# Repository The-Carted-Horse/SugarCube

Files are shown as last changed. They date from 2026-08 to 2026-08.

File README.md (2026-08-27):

# GlucoCube

A wall-mounted glucose dashboard for two (or more) people, built for a
Raspberry Pi with the official 7" touchscreen. It boots straight into the
display — no desktop environment — and shows each person's current glucose,
trend, a 3-hour history chart, a 2-hour forecast, insulin on board, carbs on
board, and recent treatments.

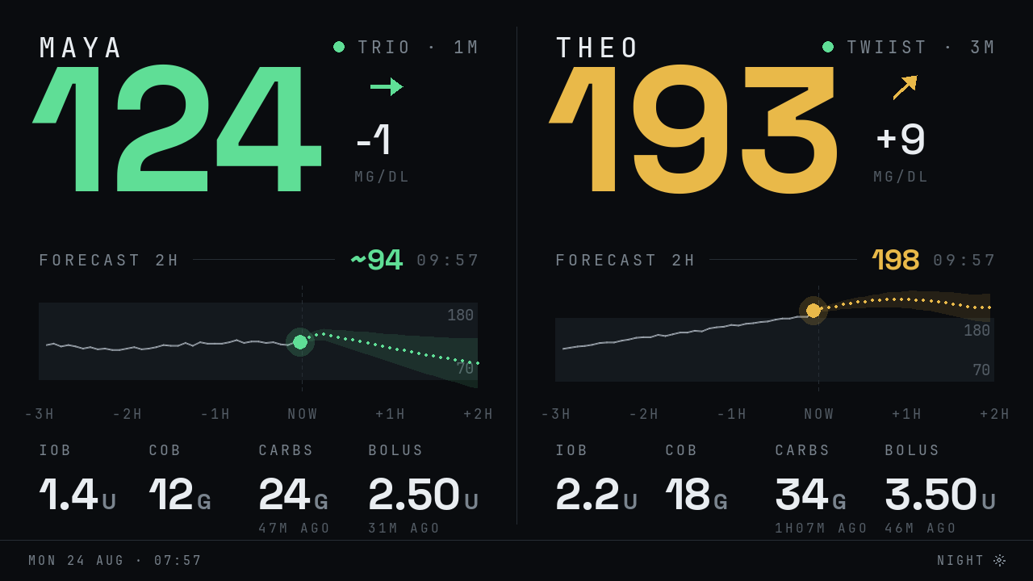
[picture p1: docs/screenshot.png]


## Features

- **Per-person data sources** — each person's data can arrive by:
  - **Push**: point a [Trio](https://github.com/nightscout/Trio) (or any
    Nightscout uploader) at the Pi — it speaks a minimal Nightscout v1 API,
    one port per person
  - **Pull from Tidepool** — for the twiist AID system, which uploads to
    Tidepool automatically; readings, boluses, carbs, IOB/COB, and pump
    settings all come across
  - **Pull from a Nightscout site** — for people with an existing cloud
    Nightscout; API secrets and access tokens both work (auto-detected)
- **Glucose forecast** — a 2-hour forecast curve with a confidence band on
  every chart, plus the projected value 2 hours out: uses the AID system's
  own prediction when available (Trio's `predBGs`, Loop's `predicted`),
  otherwise runs an oref0-style model (exponential insulin activity,
  deviation-based carb absorption) with therapy settings pulled from the
  person's Nightscout profile or Tidepool pump settings. Estimates are
  marked with `~`.
- **Web app** — the same dashboard in any browser, auto-refreshing,
  responsive, with light/dark themes. Settings (people, sources, thresholds)
  and a sync log are managed from the browser too; no SSH needed after
  install. Works great through a Cloudflare tunnel.
- **Touchscreen controls** — tap the sun/moon on the display for light or
  dark, and **SETTINGS** beside it to pop a QR code that opens the
  settings page on a phone, already signed in. The panel is read directly
  from `/dev/input`, so both work on the ready-made image as well as on a
  manual install; the theme switch is on the settings page too.
- **Update channels** — standard releases, or beta with the pre-releases
  as well; switching channels moves the device onto that channel's newest
  release straight away.
- **Per-person thresholds** — low/high/urgent ranges per person, with
  global defaults.
- **mg/dL or mmol/L** — chosen under **Settings → Ranges**, or followed from
  a paired GlucoCore account. Readings, the change since the last one, the
  forecast and the chart's band all read in it, on the display and in the
  web app. Everything stored stays mg/dL, `/api/dashboard.json` included, so
  switching converts what is shown rather than moving any threshold.
- **Guided setup from a phone** — a fresh device shows a QR code that opens
  a step-by-step wizard: Wi-Fi, where in the world it is so the clock is
  right, and the pairing code from GlucoCore that says who it shows, one
  question per screen. Credentials are
  tested before they're saved, and nothing is written until the last step.
  With no network at all the device opens its own setup hotspot — join it
  and the wizard opens by itself, no second QR code to scan. Once a network
  is chosen the device reboots onto it and shows its new address (also
  reachable as `http://glucocube.local/` on the ready-made image).

## Install

### Option A: flash the ready-made image

Grab `glucocube-<version>.img.xz` from the
[releases page](https://github.com/The-Carted-Horse/SugarCube/releases),
flash it with Raspberry Pi Imager (or `dd`), boot the Pi, and follow the
QR codes on screen. That's the whole install.

(Images are built by the `Build and release` GitHub Actions workflow, which
runs on every push to `main` — see [Cutting a release](#cutting-a-release).)

### Option B: install on an existing Raspberry Pi OS

Use Raspberry Pi OS **Lite** (no desktop needed):

```bash
curl -sSL https://raw.githubusercontent.com/The-Carted-Horse/SugarCube/main/install.sh | bash
```

The installer handles everything: dependencies, config with random secrets,
console screen-blanking, and a systemd service that starts on boot. It
finishes by printing the URL and API secret for each person's uploader.

## Connecting the data

- **Trio (push)**: in Trio, Settings → Services → Nightscout, set URL
  `http://<pi-ip>:<port>` and the person's API secret (both shown by the
  installer and on the web settings page).
- **twiist**: the wearer links their My twiist Portal account to a free
  [Tidepool](https://www.tidepool.org) account (one-time), then enter the
  Tidepool login in the web settings under their data source.
- **Nightscout**: enter the site URL and its API secret or access token.
- **GlucoCore**: three ways in, under **Settings → GlucoCore** or during
  guided setup, and they end in the same place.
  - **Scan it.** An unpaired display asks GlucoCore to pair it and shows the
    request as a QR code, on its own screen and on the settings page. Scan it
    with a phone that is signed in, choose who the display shows, approve —
    and it pairs itself. Nothing is typed at the display, and it never
    handles the account password. The code on the wall carries a request id
    and nothing else; the secret that collects the token stays on the device.
  - **Sign in on the display.** Email and password, used once to create the
    display in GlucoCore. Only the read-only device token is kept.
  - **Type a pairing code.** In GlucoCore, open **Devices** and create one:
    six digits, ten minutes, single use.

  Pairing adds those people to the display — anyone already fed by Trio,
  twiist or Nightscout keeps the source they have. Who appears, what they are
  called and their ranges then follow what GlucoCore says. Unpairing turns
  them back into uploader-fed people, each with their own port and API
  secret.

## The web app

Everything is served on plain HTTP port 80 — open `http://glucocube.local/`
(or the IP shown on the device's screen; HTTP Basic auth, login shown
there too). Every QR code the device puts on its screen carries the login
with it, so scanning one opens the page signed in — tap **SETTINGS** in
the footer of the display to get one for the settings page. The password
is printed under each code for anyone typing the address by hand.

The installer sets a random password, and **Access** can turn it off
again: on a home network you trust, the device is only reachable from
that network, and no password means nothing to look up on a phone. Then
the settings hub stops asking you to set one. On a network guests,
flatmates or an office share, keep it.

The `.local` name needs mDNS — iPhones, Macs, Windows, and Android 12+
all resolve it; on older Android type the IP instead. When port 80 isn't
available (e.g. running by hand on a dev machine) it falls back to 8080.

| Path | What |
|---|---|
| `/` | Live dashboard (auto-refreshes every 30s) |
| `/setup` | Guided setup, one question per screen |
| `/settings` | Everything else, one page per thing |
| `/log` | Sync activity from every data source |
| `/screen.png` | What the physical screen shows right now |
| `/api/dashboard.json` | The dashboard's data, as JSON |

Settings is a hub rather than one long form: each row says what it is set
to now — who is configured and when their last reading arrived, the
ranges, the network, the time zone, the version and channel — and opens a
short page for that one thing. Every person has their own page, with only
the fields their data source actually needs. Saving restarts the display
(a few seconds) and the page waits for it to come back rather than
guessing.

| Page | What is on it |
|---|---|
| `/settings/screen` | Live view of the physical screen, and Day/Night |
| `/settings/people` | One row per person, then a page each |
| `/settings/glucocore` | Pair this display with a GlucoCore code, or unpair it |
| `/settings/ranges` | mg/dL or mmol/L, in-range and urgent thresholds, staleness |
| `/settings/network` | Wi-Fi: what it is on, and what else is nearby |
| `/settings/clock` | Time zone (with what your phone thinks it is) |
| `/settings/updates` | Version, release channel, install |
| `/settings/access` | Password (or none at all), and a link that opens settings without logging in |

## Wi-Fi setup

A device with no network opens its own `GlucoCube-Setup` hotspot and shows
a QR code that joins a phone to it. Once the phone is on that hotspot the
setup page opens by itself — the device answers the connectivity check
every phone makes on joining a network, which is what makes the "sign in
to network" sheet appear. The page lists the networks the device saw
before the hotspot came up: tap one, or choose **Other network** for a
hidden or out-of-range one, and enter the password (with a Show button,
so you can check it before committing).

The hotspot drops while the device tries to connect, so the phone loses
that page; that is expected. If the join succeeds the device reboots, its
screen shows the new address, and reopening setup picks up where you left
off. If it fails, the hotspot comes back within a minute or two and **the
reason appears both on the device's own screen and at the top of the page**
(wrong password, network not found, and so on) — no SSH needed to find out
what went wrong.

### What a paired display takes from GlucoCore

Who it shows and in what order, what they are called, the in-range and
urgent bands, the time zone, the clock format, the staleness cutoff — and
the backlight: a daytime brightness and a dimmer night-time one, with the
hours between which the night figure applies (equal hours mean never).
Dimming needs a panel with a backlight under `/sys/class/backlight`, which
the official 7" display has and an HDMI monitor does not; without one the
setting is simply ignored.

It also takes how the people share the screen, and the art behind them —
see [Ambient mode](#ambient-mode). A background chosen in GlucoCore is
fetched once and kept, so a display redraws from its own copy and only
re-downloads when the picture actually changes.

GlucoCore can still send settings this display does nothing with — the
alert toggles, because this is not an alarm device (see
[Safety note](#safety-note)). Each config push logs what it did not apply,
so "I changed it and nothing happened" has an answer in
[`/log`](#the-web-app).

### Ambient mode

A second way to draw the screen, for a display that lives on a nightstand
or a desk rather than a kitchen wall: **one person at a time, full-bleed,
over a background**, with the time and the weather in the corner and
everything else anchored out of the middle so the picture stays visible.
The two-panel dashboard is unchanged and is still what a display shows by
default; **Settings → The screen** switches between them, and a tap on the
ambient screen brings the usual footer back for a few seconds so the
sun/moon and the settings QR are still one press away.

Backgrounds come from three places: four the device draws itself, anything
uploaded on a person's settings page, and anything chosen in GlucoCore. A
person can have their own, the display can have one for everyone else, and
a person can be set to *nothing* — which is not the same as unset, and is
how you keep a picture off one person on your own wall when they have
chosen one for themselves.

The art is dimmed, by a figure you set, and dimmed further overnight. That
is not a style choice: the reading has to stay readable over whatever is
behind it. For the same reason the border carries the glucose state
whatever the picture is doing, a stale reading still goes grey and drops
its arrow, and **an urgent reading holds the screen** rather than taking
its turn — see the [Safety note](#safety-note).

The weather is off until you say where the device is, under
**Settings → Weather**. It asks [Open-Meteo](https://open-meteo.com/),
which needs no account and no key, every fifteen minutes; a town name is
looked up once, when you save it. Guessing a location from the time zone
would need a coordinate table on the device and would confidently show the
wrong town's sky, so it does not.

### From GlucoCore's devices screen

A paired display collects the commands queued for it — on its realtime
channel when it has one, otherwise within the minute — and says what it
did with each, so the devices screen shows the outcome rather than a
silence:

| Command | On this display |
|---|---|
| Identify | Flashes a band across the screen for 30 seconds |
| Restart | Restarts the display; it comes back in a few seconds |
| Refresh now | Polls every pull source immediately |
| Clear cache | Drops stored readings and fetches again (therapy settings stay) |
| Check for updates | Runs the release check, and installs a forced release |

The heartbeat carries the version it is running and the config version it
has applied, which is what lets that screen tell a display that is behind
from one that is simply offline.

## Updates

### Upgrading from 1.x (SugarCube)

**Re-flash the card.** Version 2 renames the Python package, the service and
the paths, and 1.x's updater cannot install it: it looks for a package by the
old name. What happens when you press Install depends on how 1.x was put on:

- **From the ready-made image** — the update fails before anything is
  touched. The device carries on running 1.x, and simply never updates again.
- **From `install.sh` (a git checkout)** — do not press Install. The checkout
  succeeds, the service is left pointing at a module that no longer exists,
  and it restart-loops with no automatic way back. Recovering needs SSH.

Flashing a version 2 image is the supported route, and settings are entered
again through the setup wizard. To keep a 1.x device exactly as it is, leave
it alone — it will offer the update but cannot complete it.

The device checks GitHub for new [releases](https://github.com/The-Carted-Horse/SugarCube/releases)
every 6 hours. When one is available it shows up on the display footer, the
web dashboard, and the settings page — install it from **Settings →
Updates** (the display restarts, data is untouched). A release whose notes
contain `[force-update]` installs itself automatically at the device's next
check — use that for fixes every device should have.

### Release channels

**Settings → Updates** chooses which releases a device follows:

- **Standard** — full releases only, the ones `main` publishes. The default.
- **Beta** — the pre-releases `dev` publishes as well, for anyone happy to
  find the rough edges first.

Changing the channel installs that channel's newest release immediately,
rather than waiting for the next thing to be published. Leaving Beta
therefore steps *back* onto the last full release, which is the point: the
channel decides which releases the device runs, not just which ones it is
told about. A device that ends up on a pre-release with Standard selected
says so on the settings page, and offers the way back.

The channel is stored in `config.json`:

```json
{ "updates": { "channel": "beta" } }
```

### Cutting a release

Releases are cut by pushing, not by tagging:

- **Push to `dev`** — builds an image and publishes `vX.Y.Z-rc.N` as a
  GitHub *pre-release*. Devices on the Standard channel never see it;
  devices set to Beta are offered it at their next check, and the attached
  image can be flashed to try it. Each further push to `dev` bumps `N`.
- **Push to `main`** — builds an image and publishes `vX.Y.Z` as a full
  release. This is the one existing devices offer under Settings → Updates.
  It takes the version the `dev` rcs were rehearsing (`2.0.1-rc.3` →
  `2.0.1`), or bumps the patch number if `dev` never rehearsed one.

Both create their tag at the commit that was pushed, so there is no tag to
push by hand.

For a minor or major bump — or to run either channel off another branch —
run the workflow manually and pick the part to increment and the channel.

A push that changes nothing a device runs publishes nothing: prose, the
enclosure, the test suite and tool config are excluded on both channels,
because a release whose code is identical to the last one would still be
offered to every device on it. Everything else still cuts one, `install.sh`
and the systemd units included. To publish anyway, run the workflow by
hand — the exclusions apply to pushes only.

## Enclosure

[`enclosure/`](enclosure/) has a printable OpenSCAD enclosure for the 7"
display module — see `enclosure.scad` and the ready-to-slice STLs in
`enclosure/build/`. It was designed by Sarah Sabanis and is licensed
separately, under [CC BY-NC-SA 4.0](enclosure/LICENSE).

## Development

Runs on a Mac/PC in a window with fake data:

```bash
pip install pygame qrcode
python -m glucocube --demo --windowed
```

`--no-display` runs the servers headless — useful for working on the web UI,
since nothing it serves needs pygame. `--screenshot out.png` renders one
frame and exits.

If the touchscreen is mounted rotated relative to the panel, correct it
with `GLUCOCUBE_TOUCH_TRANSFORM` — a comma-separated list of `swap`,
`invx` and `invy` — in the systemd unit. `GLUCOCUBE_TOUCH=off` disables
reading the panel altogether. The runtime dependencies are `pygame` and
`qrcode`, plus `websocket-client` for GlucoCore's realtime channel — a
config change then reaches the display in seconds rather than at the next
poll, and without the package it long-polls instead. All three come from
apt on the Pi; everything else is the Python standard library.
The display and web app are typeset in
[Space Grotesk](https://github.com/floriankarsten/space-grotesk) and
[JetBrains Mono](https://github.com/JetBrains/JetBrainsMono), bundled under
the SIL Open Font License in `glucocube/fonts/`.

### Tests

The suite is standard `pytest`, and needs no hardware — the display is
rendered through SDL's dummy driver (the same one the shipped image uses),
NetworkManager and every outbound HTTP call are stubbed out, and the
end-to-end tests start `python -m glucocube` in a subprocess and talk to
it over sockets:

```bash
pip install -r requirements-dev.txt
pytest                       # the whole suite, about fifteen seconds
pytest tests/test_oref.py    # one module
pytest --cov=glucocube       # with coverage
ruff check glucocube tests   # the same lint CI runs
```

The `Tests` workflow runs all of it on Python 3.11, 3.12 and 3.13,
alongside `shellcheck` over `install.sh` and the image stage scripts and
`systemd-analyze verify` over the service units. The release build calls
that same workflow and waits for it, so nothing is published from a red
tree.

## Safety note

This is a convenience display, not a medical device. Forecasts are estimates
— even the pump-provided ones. Don't rely on it for alarms or treatment
decisions; use the CGM app's own alerts for that. The same, in operative
terms, is in [`LICENSE`](LICENSE), so that it travels with every copy.

## License

GlucoCube is free to use for personal and other noncommercial purposes,
under the [PolyForm Noncommercial License 1.0.0](LICENSE) — that covers
personal and hobby use, study and research, and use by charities, schools,
public health bodies and government, whatever their funding. Commercial use
needs written permission: open an issue to ask.

Three things in this repository are **not** under those terms:

- The **enclosure** is Sarah Sabanis's design, under
  [CC BY-NC-SA 4.0](enclosure/LICENSE).
- The **bundled fonts** in `glucocube/fonts/` stay solely under the SIL Open
  Font License 1.1. Your rights in them, commercial use included, are
  untouched by the license above — the OFL requires exactly that.
- The **SD card image** is Raspberry Pi OS, and every package in it keeps its
  own license. GlucoCube's terms reach only the GlucoCube layer.

The glucose forecast reimplements the exponential insulin-activity model
from [oref0](https://github.com/openaps/oref0) in Python. Raspberry Pi,
Nightscout, Trio, Tidepool, twiist, Loop and OpenAPS are their owners'
names, used here only to say what works with what.

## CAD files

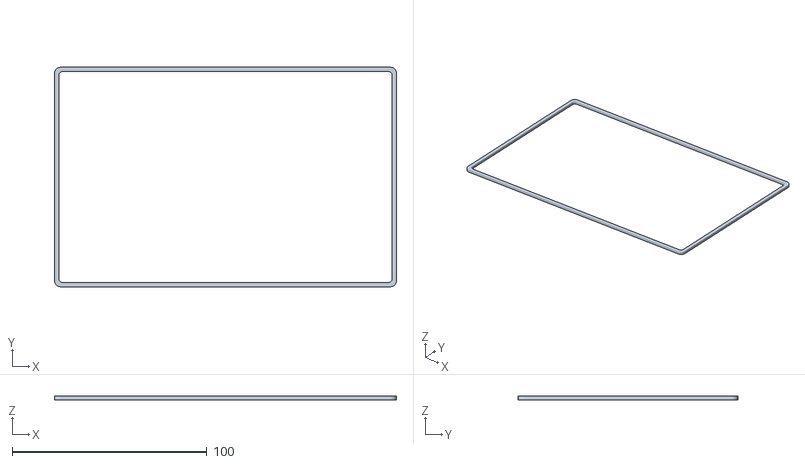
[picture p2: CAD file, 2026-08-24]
enclosure/build/gasket_flange.stl
175.7 x 112.8 x 1.80

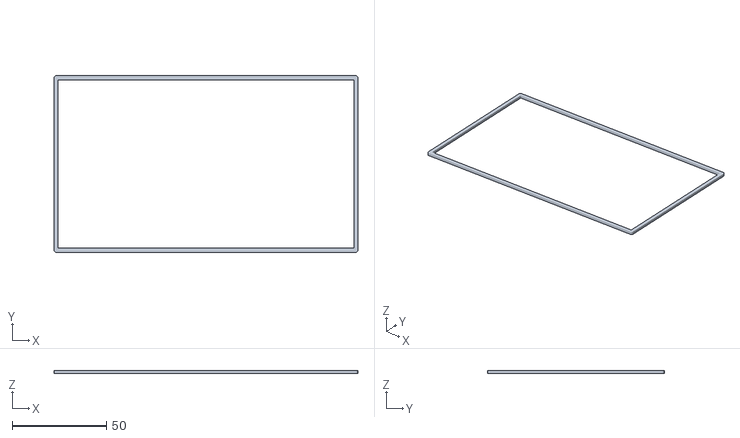
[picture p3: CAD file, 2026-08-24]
enclosure/build/gasket_window.stl
161.5 x 93.8 x 1.80

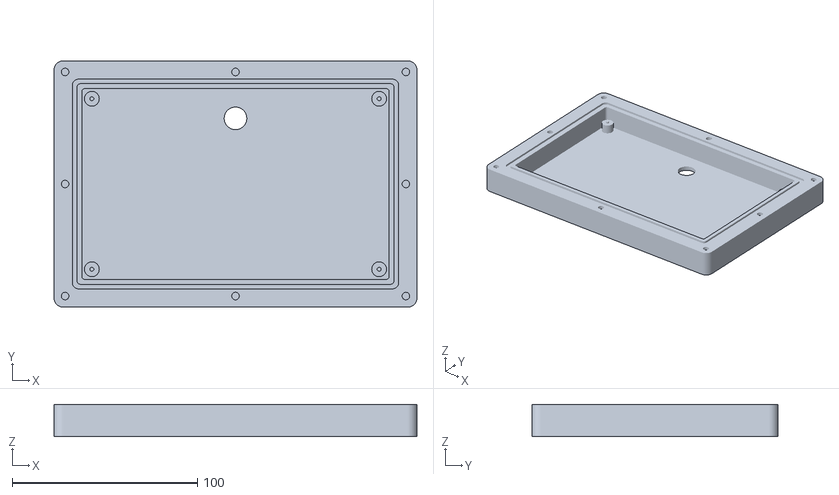
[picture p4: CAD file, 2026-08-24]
enclosure/build/rear.stl
195.7 x 132.8 x 17.4

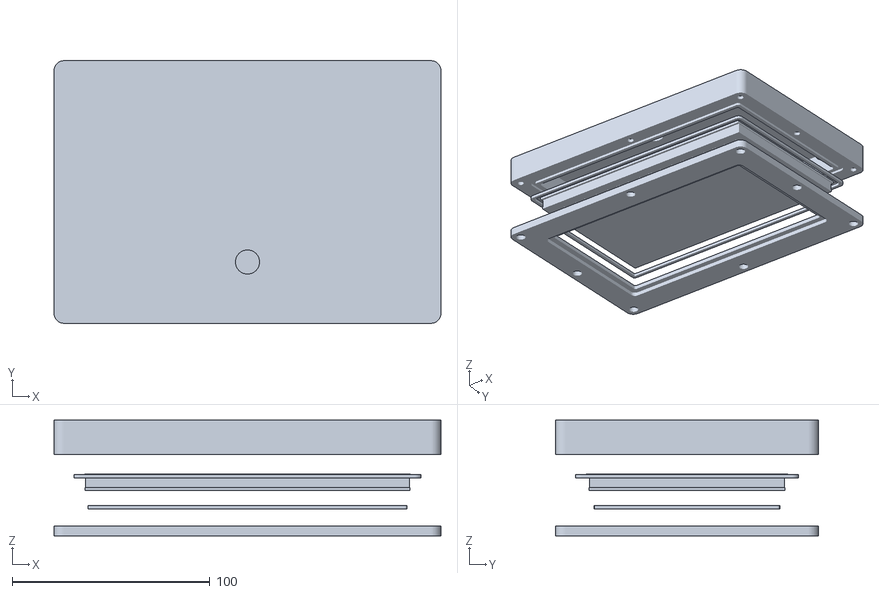
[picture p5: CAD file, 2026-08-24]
enclosure/build/preview.stl
195.7 x 132.8 x 58.5

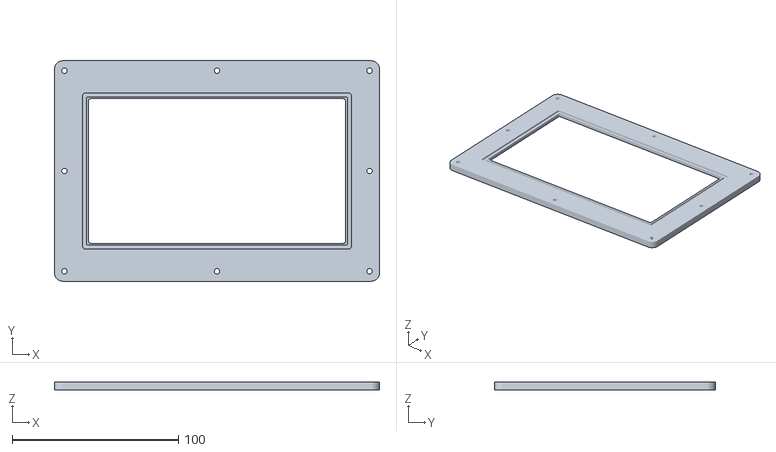
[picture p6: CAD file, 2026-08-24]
enclosure/build/front.stl
195.7 x 132.8 x 5.00

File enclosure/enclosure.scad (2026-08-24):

// Airtight enclosure for a 7.0" 800xRGBx480 LCM+CTP module
// Dimensions from the module drawing (mm).
//
// Coordinates: origin at the display center in XY.
// Z = 0 is the front face of the lens. +Z is toward the rear.
//
// Three seals keep the cavity closed:
//   1. Window gasket — front bezel against the lens glass
//   2. Flange gasket — front bezel against the rear housing
//   3. M12 cable gland — sealed cable exit through the back wall
//
// The module is located by four pins in the outer mounting holes and
// clamped by the bezel. No screw path enters the sealed volume.
//
// In Customizer, set `part` and export STL for each piece.
// Print front/rear in PETG or ASA, 5+ perimeters, 0.2 mm layers.
// Print gaskets in TPU 95A, or seat 2 mm silicone cord in the grooves.

/* [Export] */
part = "preview"; // [preview, front, rear, gasket_window, gasket_flange]

/* [Fit] */
fit_clearance = 0.40;       // extra per side around the PCB
rear_extra = 2.20;          // spare depth behind rear components

/* [Walls] */
wall = 3.00;
flange = 12.00;             // flange width beyond the tub wall
front_thick = 5.00;         // front bezel thickness at the flange
lip_thick = 2.60;           // bezel thickness over the glass
corner_r = 5.00;

/* [Screws] */
screw_d = 3.30;             // M3 clearance
screw_head_d = 6.20;
screw_head_h = 3.20;
insert_d = 4.10;            // M3 heat-set insert
insert_h = 6.20;
screw_inset = 6.00;         // outer edge to screw center

/* [Gaskets] */
gasket_w = 2.20;
gasket_h = 1.80;            // uncompressed TPU (or 2 mm cord)
groove_w = 2.40;
groove_h = 1.45;            // ~20–25% compression at full clamp
window_gasket_inset = 1.10; // window edge to inner groove edge

/* [Cable gland] */
gland_enable = true;
gland_d = 12.20;            // M12x1.5 through-hole in the back wall

/* [Hidden] */
eps = 0.08;
$fn = 48;

// --- datasheet (mm) -------------------------------------------------------
pcb_w = 164.90;
pcb_h = 102.00;
pcb_t = 1.60;

lens_w = 164.28;
lens_h = 99.17;
lens_t = 1.50;

va_w = 154.68;
va_h = 87.02;

aa_w = 154.12;
aa_h = 85.98;

lcm_ctp_t = 5.15;
to_pcb_back = 8.25;
total_t = 12.25;

outer_hole_dx = 154.89;
outer_hole_dy = 91.92;
pin_d = 2.20;
pin_h = 1.20;
pad_d = 8.00;

inner_hole_dx = 58.00;
inner_hole_dy = 49.00;
inner_from_top = 35.19;
inner_from_right = 46.54;

// --- derived --------------------------------------------------------------
inner_w = pcb_w + 2 * fit_clearance;
inner_h = pcb_h + 2 * fit_clearance;
inner_r = 1.50;

outer_w = inner_w + 2 * wall + 2 * flange;
outer_h = inner_h + 2 * wall + 2 * flange;
outer_r = corner_r;

window_w = va_w;
window_h = va_h;
window_r = 1.20;

rear_inner_z = total_t + rear_extra;
rear_outer_z = rear_inner_z + wall;
pad_h = rear_inner_z - to_pcb_back;

groove_path_w = inner_w + 2 * wall + groove_w + 1.80;
groove_path_h = inner_h + 2 * wall + groove_w + 1.80;
groove_path_r = 3.20;

win_groove_in_w = window_w + 2 * window_gasket_inset;
win_groove_in_h = window_h + 2 * window_gasket_inset;
win_groove_out_w = win_groove_in_w + 2 * groove_w;
win_groove_out_h = win_groove_in_h + 2 * groove_w;

gland_x = 0;
gland_y = -inner_h / 2 + 16;

assert(win_groove_out_w < lens_w - 0.8,
       "Window gasket does not fit on the lens land");
assert(win_groove_out_h < lens_h - 0.8,
       "Window gasket does not fit on the lens land");
assert(lip_thick > groove_h + 0.8,
       "Front lip is thinner than the window gasket groove");
assert(pad_h > 4.2,
       "Rear pads are shorter than the component stack");
assert(insert_h < rear_outer_z - 1.0,
       "Inserts break through the rear wall");

// --- 2D helpers -----------------------------------------------------------
module rounded_rect(size, r) {
    r2 = min(r, min(size.x, size.y) / 2 - 0.05);
    offset(r = r2)
        offset(delta = -r2)
            square(size, center = true);
}

module groove_2d(path_size, width, r) {
    r_out = min(r, min(path_size.x, path_size.y) / 2 - 0.05);
    r_in = max(0.40, r_out - width * 0.45);
    difference() {
        rounded_rect(path_size, r_out);
        rounded_rect(
            [path_size.x - 2 * width, path_size.y - 2 * width],
            r_in
        );
    }
}

function hole_xy(dx, dy) = [
    [ dx / 2,  dy / 2],
    [-dx / 2,  dy / 2],
    [ dx / 2, -dy / 2],
    [-dx / 2, -dy / 2]
];

function perimeter_screws() =
    let (
        x = outer_w / 2 - screw_inset,
        y = outer_h / 2 - screw_inset
    ) [
        [ x,  y], [-x,  y], [ x, -y], [-x, -y],
        [ x,  0], [-x,  0], [ 0,  y], [ 0, -y]
    ];

// --- dummy display (preview only) -----------------------------------------
module display_dummy() {
    color("#1c1c1c")
        translate([0, 0, to_pcb_back - pcb_t])
            linear_extrude(pcb_t)
                square([pcb_w, pcb_h], center = true);

    color("#2a3344")
        translate([0, 0, lens_t])
            linear_extrude(lcm_ctp_t)
                square([lens_w - 0.4, lens_h - 0.4], center = true);

    color("#c8d4e0", 0.50)
        linear_extrude(lens_t)
            square([lens_w, lens_h], center = true);

    color("#0a1220")
        translate([0, 0, -0.02])
            linear_extrude(0.04)
                square([aa_w, aa_h], center = true);
}

// --- front bezel ----------------------------------------------------------
module front_bezel() {
    difference() {
        translate([0, 0, -front_thick])
            linear_extrude(front_thick)
                rounded_rect([outer_w, outer_h], outer_r);

        // viewer-side recess: thinner picture-frame around the window
        translate([0, 0, -front_thick - eps])
            linear_extrude(front_thick - lip_thick + eps)
                rounded_rect(
                    [window_w + 8, window_h + 8],
                    window_r + 2
                );

        // viewing opening (datasheet V.A.)
        translate([0, 0, -front_thick - eps])
            linear_extrude(front_thick + 2 * eps)
                rounded_rect([window_w, window_h], window_r);

        // gasket groove in the glass-facing surface
        translate([0, 0, -groove_h])
            linear_extrude(groove_h + eps)
                groove_2d(
                    [win_groove_out_w, win_groove_out_h],
                    groove_w,
                    1.40
                );

        for (p = perimeter_screws())
            translate([p.x, p.y, 0])
                screw_through_front();
    }
}

module screw_through_front() {
    translate([0, 0, -front_thick - eps])
        cylinder(d = screw_d, h = front_thick + 2 * eps);
    translate([0, 0, -front_thick - eps])
        cylinder(d = screw_head_d, h = screw_head_h + eps);
}

// --- rear housing ---------------------------------------------------------
module rear_shell() {
    difference() {
        linear_extrude(rear_outer_z)
            rounded_rect([outer_w, outer_h], outer_r);

        translate([0, 0, -eps])
            linear_extrude(rear_inner_z + eps)
                rounded_rect([inner_w, inner_h], inner_r);
    }
}

module pcb_supports() {
    for (p = hole_xy(outer_hole_dx, outer_hole_dy)) {
        translate([p.x, p.y, to_pcb_back]) {
            cylinder(d = pad_d, h = pad_h + eps);
            translate([0, 0, -pin_h])
                cylinder(d = pin_d, h = pin_h + 0.40);
        }
    }
}

module rear_housing() {
    difference() {
        union() {
            rear_shell();
            pcb_supports();
        }

        translate([0, 0, -eps])
            linear_extrude(groove_h + eps)
                groove_2d(
                    [groove_path_w, groove_path_h],
                    groove_w,
                    groove_path_r
                );

        for (p = perimeter_screws())
            translate([p.x, p.y, -eps])
                cylinder(d = insert_d, h = insert_h + eps);

        if (gland_enable)
            gland_hole();
    }
}

module gland_hole() {
    translate([gland_x, gland_y, rear_inner_z - 1])
        cylinder(d = gland_d, h = wall + 2);
}

// --- printed gaskets (TPU) ------------------------------------------------
module gasket_window() {
    linear_extrude(gasket_h)
        groove_2d(
            [win_groove_out_w - 0.20, win_groove_out_h - 0.20],
            gasket_w,
            1.20
        );
}

module gasket_flange() {
    linear_extrude(gasket_h)
        groove_2d(
            [groove_path_w - 0.20, groove_path_h - 0.20],
            gasket_w,
            groove_path_r - 0.10
        );
}

// --- assembly preview -----------------------------------------------------
module preview() {
    explode = 18;

    color("SteelBlue")
        translate([0, 0, -explode])
            front_bezel();

    color("DarkOrange")
        translate([0, 0, -groove_h - explode * 0.45])
            gasket_window();

    display_dummy();

    color("DarkOrange")
        translate([0, 0, explode * 0.35])
            gasket_flange();

    color("Silver")
        translate([0, 0, explode])
            rear_housing();
}
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

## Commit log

2026-08-24 Initial release: two-person glucose wall display for Raspberry Pi
    Pygame/KMS display (no desktop) with per-person panels: current glucose,
    trend, 3h history, 2h forecast, IOB/COB, recent treatments. Data arrives
    via Nightscout-compatible push (Trio), Tidepool pull (twiist), or
    Nightscout-site pull. Forecasts use the AID's own prediction curves with
    an oref0-style fallback. Includes a web dashboard/settings/sync-log UI,
    QR onboarding with Wi-Fi hotspot provisioning, light/dark themes, and a
    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
2026-08-24 Fix image build: register qemu-aarch64 binfmt before pi-gen
    The runner lacked fix-binary binfmt registration, so ARM binaries could
    not execute inside pi-gen's container ("arm64: not supported on this
    machine/kernel").
2026-08-24 Build image on native ARM runner instead of QEMU
    The action's own binfmt registration fails on x86 ubuntu-latest runners;
    GitHub's ubuntu-24.04-arm runners run pi-gen natively and faster.
2026-08-24 Copy app source into the build stage before pi-gen runs
    pi-gen mounts only the stage directory into its container, so the
    trio_monitor package must be staged under files/ rather than referenced
    from the repo checkout.
2026-08-24 Slim the SD image
    Install stage packages without recommends (drops the SDL soundfont
    chain), explicitly keep wpasupplicant + dnsmasq-base for Wi-Fi client
    and hotspot modes, purge Bluetooth and non-Broadcom Wi-Fi firmware, and
    strip docs/man/locales.
2026-08-24 Start the setup hotspot immediately on fresh devices
    Drop the network-online boot ordering (the app does not need a network
    to start, and waiting stalled first boot for minutes) and require only
    one failed connectivity check when no Wi-Fi has ever been configured.
    Established setups keep the 3-check grace period.
2026-08-24 Wait for a connected display before video init; portrait support
    The service now starts early in boot, so wait for a DRM connector to
    report 'connected' before initializing kmsdrm — grabbing the device
    mid-probe can leave a DSI panel undriven. Setup screens scale by the
    smaller screen dimension and data panels stack vertically on portrait
    displays (e.g. Touch Display 2).
2026-08-24 Set Wi-Fi regulatory country in the image
    Without a country, rfkill blocks the radio on first boot and the setup
    hotspot can never start. Set wpa-country in the CI build and run
    raspi-config do_wifi_country in the stage as belt-and-braces.
2026-08-24 Allow changing the admin password from the settings page
    Blank keeps the current password; minimum 6 characters; applies on
    Save & Apply with the usual restart.
2026-08-24 Never hit the restart start-limit
    Early-boot crashes before the display driver is ready could trip
    systemd's default 5-failure start limit, leaving the service dead at a
    login prompt. Disable the limit; the display-ready wait handles the
    root cause.
2026-08-24 Restore the EGL/Mesa stack the no-recommends install dropped
    SDL's kmsdrm backend needs libEGL and the Mesa DRI drivers to open the
    display; without them set_mode dies with "EGL not initialized" on every
    Pi. Explicitly install libegl1, libgles2, and libgl1-mesa-dri.
2026-08-24 Add fbdev presentation mode (TRIO_DISPLAY=fbdev)
    On some Pi 4 setups SDL's EGL/GLES scanout produces black frames even
    though rendering succeeds. fbdev mode renders via SDL's dummy driver
    and copies pixels straight to /dev/fb0 — the same path the text console
    uses, with no GPU stack involved.
2026-08-24 Reopen /dev/fb0 for every frame
    The DRM fbdev emulation only flushes write() damage to the panel when
    the device closes — a persistently open fd renders into the void.
    Observed on Pi 4/vc4: frames appeared exactly when the service stopped.
2026-08-24 Force the dummy SDL driver in fbdev mode
    The service unit exports SDL_VIDEODRIVER=kmsdrm, so setdefault left SDL
    seizing the display with a blank GPU buffer while fbdev frames went to
    an unscanned buffer — revealed only when the process exited.
2026-08-24 Render fbdev frames at the framebuffer's true size
    FULLSCREEN under SDL's dummy driver substitutes a fake 1024x768 mode,
    so frames were drawn oversized and the fb copy cropped to the top-left
    corner — the panel looked zoomed in. Use a plain correctly-sized
    surface instead.
2026-08-24 Two-stage hotspot onboarding with auto-login QR
    Once a phone joins the setup hotspot (detected via ARP), the screen
    switches to a second QR that opens the settings page with a ?key= link
    that authenticates and sets a session cookie — no typed password in the
    normal flow. Generated admin passwords are now short and simple since
    they're a fallback, not the primary path.
2026-08-24 Add airtight OpenSCAD enclosure for the 7-inch display module.
    [enclosure.scad, front.stl, gasket_flange.stl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]
2026-08-24 Rebrand as SugarCube; port-80 admin, Wi-Fi reboot flow, redesigned display
    - Rename the product (package sugarcube, service/user/hostname, setup
    hotspot SSID, image stage) and point the installer at the new repo
    - Serve the web admin on port 80 (CAP_NET_BIND_SERVICE; 8080 fallback)
    so on-screen URLs need no port
    - Reboot after a Wi-Fi network is applied (polkit rule for the service
    user); never cache or show a loopback address while reconnecting, and
    bring the setup hotspot straight back after a failed join
    - Redesign the display and web dashboard: left-aligned panels with a
    source/freshness badge, FORECAST 2H headline, confidence-cone chart
    with time axis, unit-suffixed stat row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
2026-08-24 Move the enclosure into enclosure/ and link it from the README
    [enclosure.scad, front.stl, gasket_flange.stl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]
2026-08-24 Self-updates from GitHub releases; dual-stack HTTP; safer setup URLs
    - Check the latest release every 6 hours: updates surface on the display
    footer, web dashboard, and settings page (install button); releases
    marked [force-update] in their notes install themselves
    - Applying swaps the package in place (git checkout for repo installs,
    release tarball elsewhere), keeps sugarcube.prev, syntax-checks first,
    and restarts via systemd; a boot guard in the units rolls back after
    three failed starts or a missing package
    - Release versions are stamped into _version.py by CI (vX.Y.Z tags only)
    and by the updater
    - Serve all HTTP dual-stack (IPv6+IPv4, like sshd): mDNS clients resolve
    the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
2026-08-24 Fix Wi-Fi provisioning over the setup hotspot, and say why it failed
    The settings page scanned for networks inline, and nmcli cannot scan
    while the radio runs the hotspot: the page blocked for the full 30s
    timeout, the network list came back empty, and with no way to type an
    SSID there was nothing to submit — every failure silent.
    - Scan into a cache while the device is still online (and once more just
    before the hotspot comes up); the settings page only reads that cache,
    so it renders instantly in AP mode
    - Offer a datalist-backed field: pick a scanned network or type one,
    plus a hidden-network option; an empty SSID gets a real page, not a
    bare 400
    - Record every attempt in the s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
2026-08-24 Read the touchscreen directly so the NIGHT/DAY toggle works again
    The image runs the display with SUGARCUBE_DISPLAY=fbdev, which forces
    SDL's dummy video driver. That driver pumps no events and never opens
    /dev/input, so pygame saw no taps at all and nothing ever reached
    toggle_theme() — the toggle was dead on every flashed device while it
    kept working on kmsdrm installs.
    Add touch.py: a standard-library evdev reader that finds the panel under
    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
2026-08-24 Add the mobile UI toolkit, and the shared pieces onboarding needs
    Everything the device serves is read on a phone first — onboarding happens
    over the setup hotspot, where the browser has no internet — but the admin
    pages were built desktop-first with 11rem labels beside 16rem inputs, which
    is 432px of fixed layout on a 390px screen.
    ui.py holds the replacement: one mobile-first stylesheet, one page() shell
    so no response can ship without a doctype, a viewport and styles again, and
    components for the things hand-written markup kept getting wrong — password
    fields you can reveal, options you can tap, and conditional sections
    rendered hidden by the server instead of hidden by a script at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
2026-08-24 Rebuild the settings page around the phone it is used on
    The page the setup QR code sends you to had no media query at all, and
    laid out an 11rem label beside a 16rem input — 432px of fixed width on a
    390px screen — with inputs small enough that iOS zoomed the page on every
    tap. It now stacks on a phone and widens at 640px, every control is at
    least 44px, and each of the reported problems is gone:
    - The port and the push API secret sat outside the show/hide machinery,
    so a twiist user was asked for a "Port (Nightscout API)" they will
    never use. They now belong to the push source like everything else, and
    the source is chosen from tappable cards rather than a dropdown that
    hides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
2026-08-24 Add a guided setup wizard, and point the QR codes at it
    A fresh device's QR code opened /settings: the live screen, Wi-Fi,
    updates, every person, every threshold and the admin password, all on one
    page, in a form laid out for a desktop. That is a reference page, not an
    introduction. /setup asks one thing at a time — Wi-Fi, who it is for,
    where each person's data comes from, the credentials for it, ranges, a
    password — with a progress bar and one primary action per screen.
    Nothing is written to config.json until the last step. Answers accumulate
    in a draft in the store, so the wizard survives the reboot that joining
    Wi-Fi causes and picks up where it left off, and abandoning it halfway
    l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
2026-08-24 Open setup by itself when a phone joins the setup hotspot
    Getting onto the setup page took two QR codes: one to join the hotspot,
    then a second, scanned off the device's screen, to reach the page. The
    second one is now unnecessary.
    A phone fetches a known URL the moment it joins a network to check
    whether it really reaches the internet. Two pieces make that check land
    on setup: a NetworkManager shared-mode dnsmasq rule resolving every name
    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
2026-08-24 Keep blank form fields, and document the new setup
    parse_qs drops blank values by default, and both save paths scan for
    u0_name, u1_name, ... to find their people. A person left blank ended
    that scan early and silently discarded everyone after them — adding a
    third person and not naming the second lost the third. Blank values are
    now kept, which the credential fields already depended on to mean
    "unchanged".
    Clearing a saved person's name is treated as the slip it almost always
    is, and says to use Remove instead; a row that was added and never filled
    in is simply skipped. The wizard's people step offers one spare name slot
    beyond whoever is already there, so a second person can be named wi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
2026-08-24 Rename SugarCube to GlucoCube
    163 occurrences across 25 files in three casings, and seven paths moved with
    git mv so history follows. No tag has ever been cut, so no image and no
    self-update has shipped: nothing needs a migration shim or a compatibility
    alias, and identifiers that would otherwise be awkward to change — the
    database filename, the auth cookie, the hotspot SSID — simply change.
    Four places needed more than a substitution, each of which fails quietly if
    missed:
    - the updater looks for the package by name inside a release tarball, keeps
    the outgoing version beside it, and names the repo it polls; the same
    package and backup names are spelled out again in the boot guard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
2026-08-24 Ask where the device is, so the clock is right
    A fresh image has no time zone set at all — the build never chose one — so
    every device came up on UTC and the wall clock was simply wrong for most of
    the world. Setup now asks, in a step placed before anything else that shows
    a time.
    The phone already knows where it is, so the first option is one tap: its own
    zone, with a line underneath reading back what the time would be there, so a
    wrong answer is obvious before it is committed. Behind that is the full list
    of zones the device knows, which is also the whole answer when JavaScript is
    off. The same control is on the settings page.
    Choosing applies immediately rather than at the end of th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
2026-08-24 Put a small cube in the middle of the footer
    A mark on the screen it belongs to, on both the wall display and the web
    dashboard: an isometric cube — a hexagon with three edges to the near
    corner — beside the name, in the faintest colour of the palette.
    Drawn rather than blitted, the way the sun and moon above it already are, so
    it is sharp on any panel and carries no asset around with it. The web copy is
    the same shape as inline SVG in currentColor, so it follows the theme without
    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
2026-08-24 Point the GitHub URLs back at the SugarCube repository
    The repository keeps its old name; only the product is GlucoCube. The rename
    rewrote every occurrence of the old name, including ten that address
    github.com rather than naming the product, and two of those are load bearing:
    the updater's REPO, which the device polls every six hours and which would
    have 404ed forever while reporting only "last check failed"; and install.sh's
    REPO_URL, which is what git clone runs, so the documented one-line install
    would have cloned nothing.
    The rest were dead links — the releases page in the README, and the Required
    Notice URL in both copies of the licence, which is the line identifying the
    licensor t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
2026-08-24 Prepare 2.0.0: signpost the upgrade break
    The rename is a breaking change for anything already running 1.x, so this
    goes out as a major version and says why in the place people look.
    A 1.x updater looks for a package under the old name and will not find one.
    From the ready-made image that fails before touching anything, and the device
    carries on as it was but never updates again. From a git checkout it is worse:
    the checkout succeeds, the service is left pointing at a module that no longer
    exists, and it restart-loops — the boot guard's fallback is only ever created
    on the tarball path, so there is nothing to roll back to. Re-flashing is the
    supported route, and the README now says so bef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
2026-08-24 Let a device choose which releases it follows
    The updater asked GitHub for "the latest release", which by definition
    skips pre-releases, so there was no way to be on the receiving end of one:
    either a build went to every device at once, or it went nowhere anybody
    could flash it without a laptop. This adds the channel that decision needs.
    stable full releases only, the same set /releases/latest answers with
    beta pre-releases as well, newest first
    The channel lives in config.json under "updates", and the checker thread
    holds the live Config object rather than a copy of the string, so a change
    takes effect on the next check instead of at the next boot.
    Two things follow from "the cha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
2026-08-24 Break settings into pages you can finish
    The settings page was one form holding everything the device knows: the
    live screen, Wi-Fi, updates, every person with their port, secret,
    credentials and four thresholds, then the shared thresholds, the time
    zone and the admin password. On the phone it is used from, that is a
    minute of scrolling to find one field, and a single Save that reaches
    all of it.
    It is now a hub of one-line rows, each opening a short page for one
    thing: the screen, people, ranges, Wi-Fi, clock, updates, access. Every
    row carries its own state — who is configured and when their last
    reading arrived, the ranges in force, the network it is on, the zone and
    the time there now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
2026-08-25 Add a CI test suite and wire it into the release build
    957 tests covering every module, and a Tests workflow that runs them on
    Python 3.11, 3.12 and 3.13 before anything is published.
    Nothing here needs hardware or a network. The display renders through
    SDL's dummy video driver — the same one the shipped image uses — so real
    frames are drawn and checked in CI; NetworkManager and every outbound
    HTTP call are stubbed at the conftest level, so a test that forgets to
    stub a poller fails loudly instead of reaching Tidepool or GitHub from a
    runner.
    The coverage follows the risk rather than the line count:
    - config.py and the settings/wizard save paths, because a config the
    loader rejects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
2026-08-25 Probe readiness with a whole HTTP request
    The end-to-end fixture waited for the app by connecting a socket and
    closing it. The handler then wrote a "bad request syntax" 400 into a
    socket that had already gone, and the broken-pipe traceback landed in the
    CI log next to a passing run — the kind of noise that costs someone ten
    minutes the next time something really does fail.
    Claude-Session: https://claude.ai/code/session_01LvXKTwc9ZrV3ihnKKfiuMg
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2026-08-25 Cover the no-password choice
    dev grew a test suite while this branch was off main, and two of its
    cases pinned the behaviour this branch deliberately changes: a blank
    field on /settings/access was an error, where it now means "keep the one
    in use" — the same thing it has always meant in the wizard, and what the
    field's own hint promises.
    Those two split into the pair they were conflating: too short is still
    refused, blank keeps the password, and blank is refused only when there
    is no password to keep. The rest is new ground — the flag that separates
    open-on-purpose from never-set, the hub going quiet for the first and not
    the second, a device with no password letting a request through w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
2026-08-26 Let a display already in use pair with GlucoCore
    Pairing only existed inside the setup wizard, and /setup redirects a
    device that is already configured straight to /settings. So a display
    showing readings had no way to reach GlucoCore at all: nothing on the
    settings site mentioned it, and the one route in — "Run guided setup
    again" — replaced every person on the device on its way through.
    Settings → GlucoCore now owns it. Sign in, name the display, tick who to
    show, and it registers and restarts; the account password is used once
    and only the read-only device token is kept, with the session held in the
    store for fifteen minutes and thrown away the moment pairing finishes.
    The same pag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
2026-08-26 Rewrite the wizard's tests, and ship the realtime dependency
    The wizard stopped asking who each person is and where their readings
    come from when it started pairing with GlucoCore, but its tests were left
    describing the wizard that used to exist: 27 of them failed on steps
    ("people", "source:N", "creds:N") the code no longer has. A red suite is
    one nobody reads, and the release build waits on it.
    The tests now describe the wizard that is there — welcome, timezone,
    account, the email check that only a signup needs, the display's name,
    who to show, ranges, password, review — and cover what the rewrite made
    newly possible to get wrong: a refused sign-in stays on its step, a
    signup waits fo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
2026-08-26 Say what a failed GlucoCore sign-in actually hit
    "Could not reach that address — check the spelling" is written for a
    Nightscout URL somebody typed. GlucoCore's address is built into the app,
    so it sent people hunting for a typo they could not have made, on a page
    with no address field on it.
    It now names what could not be reached and says the address is not theirs
    to correct, and the 404 branch stops telling a GlucoCore user their
    device is "not a Nightscout site". A typed Nightscout address still gets
    the spelling advice — that half of the branch was right.
    Both sign-ins also show the technical detail behind a disclosure, the way
    a failed Wi-Fi join already does. verify.Result has ca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
2026-08-26 Dial glucocore.app, which exists
    The client shipped pointing at app.glucocore.com. That hostname has no
    DNS record, so every sign-in — the settings page and the setup wizard
    alike — died in the resolver and reported "could not reach that address".
    Pairing has never worked on any device.
    The address is the one thing here nobody can correct from the device: it
    is not a setting and it is on no page. So it is pinned in a test now,
    along with the requests built from it, rather than left to a constant
    nobody reads. The GLUCOCORE_BASE override keeps working for a staging
    service, and is covered too.
    Claude-Session: https://claude.ai/code/s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
2026-08-26 Pair with a code, not with somebody's password
    GlucoCore has a pairing flow built for a display and this used none of
    it. The account mints a six-digit code under Devices, naming who the
    display shows; the display redeems it at /v1/sugar_cubes/claim and gets
    back a token scoped to those people — and, with it, the config saying
    who they are and what their bands are. The service's own note on the
    endpoint says why it exists: "the display signing in as its owner meant a
    Pi on a shelf holding a password, which is the thing the whole
    device-token design exists to avoid."
    So the settings page and the wizard both ask for a code now. The display
    never sees the account password, there is no sessio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
2026-08-26 Follow the redirect a POST gets, instead of reporting it
    Every sign-in and every pairing died with "GlucoCore answered with an
    error (308)". The service sits behind a permanent redirect — the usual
    apex-to-www — and urllib refuses to follow one on a POST: redirect_request
    raises for anything that is not GET or HEAD on a 307 or 308, because
    following it means re-sending the body. Sensible for a browser-shaped
    library, useless for an API client, and it is not version-dependent —
    every Python does this.
    So the client follows it: same method, same body, same headers, up to
    three hops. It stays on the service to do it — same host, or the same
    host with www put on or taken off, and never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
2026-08-26 Read glucose in mmol/L, where that is what glucose is read in
    GlucoCore has always been able to say a display reads in mmol/L, and the
    display has always ignored it: `units` was stored, served in
    /api/dashboard.json, and never looked at again. Everything on the glass
    was mg/dL. Most of the world reads mmol/L, and a wall display that can
    only say 6.7 as "121" is a wall display most of the world cannot use.
    Nothing about what is stored changes. Readings, thresholds, the forecast
    and the wire are mg/dL, the same contract the rest of the device and
    GlucoCore both run on — one unit, one comparison, nothing to get wrong on
    a device with no test suite in front of it. units.py is the last step
    be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
